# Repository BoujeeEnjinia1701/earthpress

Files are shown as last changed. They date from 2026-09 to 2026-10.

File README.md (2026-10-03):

# EarthPress

     

**Area:** Sustainable Housing · **TRL:** 3 of 9 (proof of concept on paper) · **Value-engineering target:** about $500 USD (estimated parts cost $523) · **Difficulty:** 3 of 5

A manual compressed earth block press with a lever and toggle linkage, producing stabilized soil blocks for low-carbon walls, with a simple soil test kit to choose mixes.

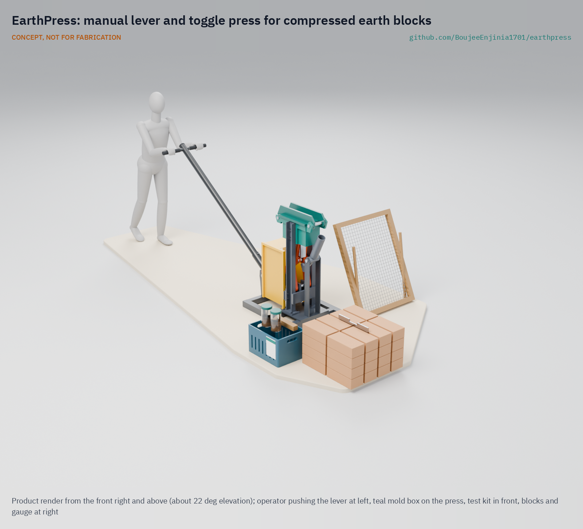
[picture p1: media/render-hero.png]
EarthPress: manual lever and toggle press for compressed earth blocks, product render


[Exploded render](media/render-exploded.png) · [Detail render](media/render-detail.png) · [Interactive 3D model](media/viewer.html) · [Concept blueprint (PDF)](media/concept-blueprint.pdf) · [General arrangement (PDF)](cad/drawings/EPR-DWG-001.pdf) · [Sizing note](docs/04-calcs/01-sizing.md) · [Decisions](docs/decisions/0002-recommendations-accepted.md) · [Prototype build plan](docs/05-build-plan.md) · [Design decisions](docs/06-design-decisions.md) · [Review note](docs/REVIEW.md)

## Concept rationale

Compressed stabilized earth blocks turn the soil on a building site into walling with a fraction of the energy of fired brick, but only if someone has a press. A manual lever and toggle press needs no fuel, power or hydraulics, can be welded from stock steel sections, and puts block making in the hands of the builder instead of a factory. The toggle suits the job because soil gets stiffer as it compacts, and a toggle's force ratio rises sharply at the end of its stroke, exactly where the force is needed.

EarthPress is open hardware so that a local welder can build, repair and adapt it without license fees or a distant supplier, and so that the soil test kit and mix guidance travel with it. The press and soil kit come to about $523 in parts (indicative), well below the thousands of dollars of hydraulic designs, and garage-buildable with a stick welder, grinder and drill press.

## Burning platform

Buildings and construction account for about 32 % of global energy use and 34 % of global CO2 emissions ([UNEP, 2025](https://www.unep.org/resources/report/global-status-report-buildings-and-construction-20242025)), and cement alone for around 8 % of global CO2 ([Chatham House, 2018](https://www.chathamhouse.org/2018/06/making-concrete-change-innovation-low-carbon-cement-and-concrete)). At the same time UN-Habitat estimates that about 3 billion people will need adequate housing by 2030, about 96,000 new affordable homes every day ([UN-Habitat](https://unhabitat.org/topic/housing)).

Meeting that demand with fired brick and cement block would lock in large emissions. Cement-stabilized earth blocks embody about 49 kg CO2/m³ against about 643 kg CO2/m³ for locally fired bricks ([Auroville Earth Institute](https://www.earth-auroville.com/compressed_stabilised_earth_block_en.php)), so the walls of a small house (about 7 m³ of blockwork) would avoid roughly 4.2 t of CO2 (estimate from EPR-CAL-001, excluding mortar and transport).

## Where it could be used

### By industry

| Industry | Use |
| --- | --- |
| Self-build and affordable housing | Families and cooperatives make walling for one- and two-room houses from site soil |
| Small construction enterprises | A block yard sells stabilized blocks to local builders as a business |
| Humanitarian and reconstruction programs | NGOs train masons and build schools, clinics and transitional-to-permanent housing |
| Agriculture | Farm stores, grain stores, animal shelters and boundary walls |
| Vocational education | Technical colleges teach earth building, soil testing and press fabrication |
| Low-carbon architecture in high-income countries | Garden walls, studios and small buildings where earthen codes allow CEB |

### By country or region

| Country or region | Why it matters there |
| --- | --- |
| Sub-Saharan Africa | 265 million people lived in slums in 2022, with an estimated 360 million more by 2030 if trends persist ([UN SDG Report 2024](https://unstats.un.org/sdgs/report/2024/Goal-11/)); soil is abundant and cement is costly |
| India and South Asia | Central and Southern Asia had 334 million slum dwellers in 2022 ([UN SDG Report 2024](https://unstats.un.org/sdgs/report/2024/Goal-11/)); India is home to the Auroville Earth Institute, a long-running center of CSEB practice, and fired-brick kilns are widespread |
| Eastern and South-Eastern Asia | The largest slum population, 362 million people in 2022 ([UN SDG Report 2024](https://unstats.un.org/sdgs/report/2024/Goal-11/)) |
| Colombia and Latin America | Soil-cement blocks were used in Colombian projects by the 1940s, and the CINVA-Ram manual press, designed at CINVA in Bogotá in 1956, spread to Bolivia, Brazil, Peru and beyond ([Botti, *Frontiers of Architectural Research*, 2023](https://www.sciencedirect.com/science/article/pii/S2095263523000584)) |
| United States (New Mexico) | The 2021 New Mexico Earthen Building Materials Code covers CEB and requires 300 psi (about 2.1 MPa) compressive strength ([14.7.4 NMAC](https://www.srca.nm.gov/parts/title14/14.007.0004.html)) |

## What sparked the idea

The starting point was the CINVA-Ram, the steel lever press that Chilean engineer Raúl Ramírez designed in 1956 at the Inter-American Housing Center (CINVA) in Bogotá and patented in 1958. Self-help housing programs then carried it as far as Ghana and South Vietnam, showing that one hand-operated press could put earth-block walls within reach of families building their own homes ([Botti, *Frontiers of Architectural Research*, 2023](https://www.sciencedirect.com/science/article/pii/S2095263523000584)). Seventy years on, that pattern still has no open, dimensioned and calculated successor that a local welder can build, while the best-documented open press, the Open Source Ecology CEB Press, is hydraulic and costs $3,000 to $6,500 in materials ([OSE wiki](https://wiki.opensourceecology.org/wiki/CEB_Press)). EarthPress sets out to update the CINVA-Ram idea with a toggle sized by calculation, a soil test kit and open drawings.

## Problem

Fired bricks and cement blocks carry high embodied carbon and cost; compressed earth blocks are proven but good presses are expensive or hard to source. Design with, not for: requirements must come from co-design sessions with builders and masons through a local partner (see [docs/01-problem.md](docs/01-problem.md)).

## Concept

A manual compressed earth block press with a lever and toggle linkage, producing stabilized soil blocks for low-carbon walls, with a simple soil test kit to choose mixes. A 1.7 m lever drives a toggle under the piston to compact a weighed fill of moist, sieved soil into a 290 x 140 x 90 mm block at 2 MPa (81 kN); the same lever, moved to an eject socket, pushes the block out. The TRL 3 sizing note (EPR-CAL-001) gives a force ratio of 173:1 at the stop and a peak pull of 668 N, so two people share the lever on a T-handle. Estimates: about 296 blocks a day with a crew of four, and, since the design was made buildable on 2026-10-01 ([EPR-DDR-003](docs/decisions/0003-design-for-construction.md)), a press of about 200 kg in pieces of 45 kg or less and about $523 in parts. Against the targets Amish accepted on 2026-09-25 ([EPR-DDR-002](docs/decisions/0002-recommendations-accepted.md)), R7 is met on paper against the 200 kg total, including the guard and bolts, that Amish set on 2026-10-02 (see the [design decisions register](docs/06-design-decisions.md)), and R13 is USD 23 over its $500 value-engineering target; R2 (pressure) and R4 (output) are at risk. See the [review note](docs/REVIEW.md).

Full design precis: [docs/02-concept.md](docs/02-concept.md)

## Key components

1. Frame on skids, in two bolted pieces
2. Steel mold box
3. Ribbed lid with hinge and latch
4. Piston and push rod
5. Toggle links, pins and bushes
6. Lever, crank hub and T-handle (removable)
7. Eject lever, rest catch and end pawl
8. Soil sieve, 5 mm mesh
9. Soil test kit
10. Block gauge

The priced bill of materials is in [bom/bom.csv](bom/bom.csv) (13 lines; lines 11 to 13 are hardware, consumables and the linkage guard). Numbers match the [exploded view](media/exploded.png). Geometry comes from the parametric model in [cad/src/model.py](cad/src/model.py), with STEP and STL exports in `cad/step` and `cad/stl`.

## Building the prototype

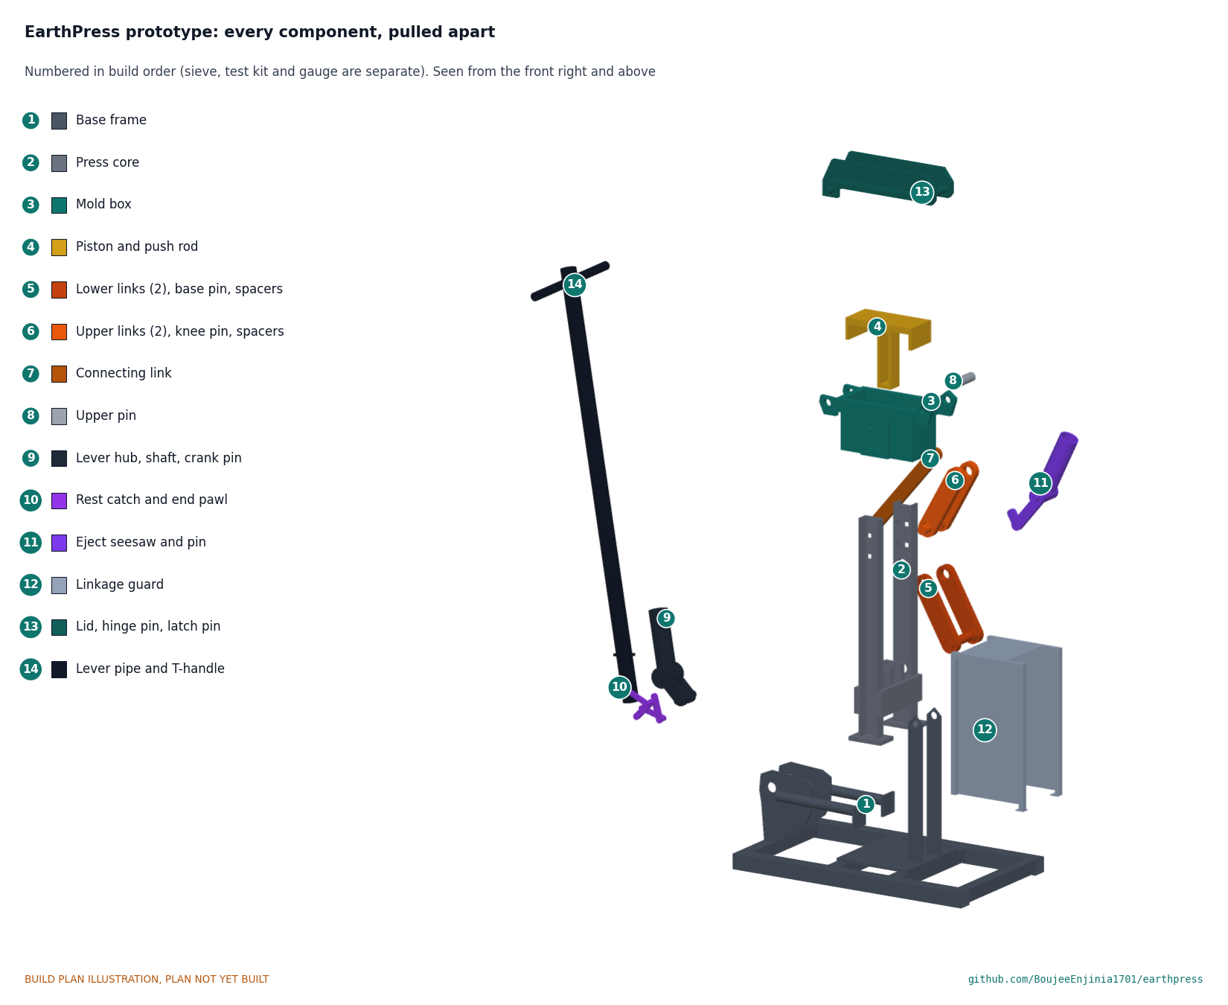
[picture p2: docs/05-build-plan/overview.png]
EarthPress prototype: every component pulled apart and numbered in build order


The [prototype build plan](docs/05-build-plan.md) (EPR-BLD-001) shows how to make each of the 14 press components and fit them together in 13 steps, with a making sketch for every made part (EPR-DWG-101 to 115) and a picture of every joint and step. The press is welded from plate, UPN 80 channel, tube and pipe in a small fabrication shop; the turned pins, shaft and bushes are bought. Making the concept buildable changed how parts join, not what the press does: the columns face the mold with their webs, the lid's hinge and latch are pins through rib ears, a spring catch and pawl hold the crank, and a central arm ejects the block ([EPR-DDR-003](docs/decisions/0003-design-for-construction.md)). It is a plan, not yet built; building and testing to it is TRL 4 work.

## Safety

> High lever forces: the piston applies 81 kN at 2 MPa and up to 173 kN if two people pull hard at the stop. Keep hands clear of the mold, linkage and eject arm, engage the end pawl before letting go (the lever kicks back with about 47 J), and never unlatch the lid until the lever is back on its rest stop. Cement burns skin and eyes, and sieving dry soil raises silica dust: wear gloves, eye protection and a respirator. Use two-person lifting for the press parts (up to 45 kg each). Blocks are not certified; structural use needs an engineer and block tests under the local code. See the safety section of [docs/02-concept.md](docs/02-concept.md).

## Repository layout

| Folder | Contents |
| --- | --- |
| `docs/` | Problem, concept, requirements, calculations and design decisions |
| `cad/src/` | build123d Python source, the source of truth for all geometry |
| `cad/step/`, `cad/stl/` | Exported models for FreeCAD, other CAD tools and printing |
| `cad/drawings/` | 2D sketches and dimensioned drawings |
| `bom/` | Bill of materials |
| `electronics/` | KiCad schematics and PCB layouts |
| `firmware/` | Microcontroller code |
| `media/` | Renders, perspectives and photos |
| `build-log/` | Dated prototyping notes |

## Documentation

Controlled documents follow the portfolio [documentation standard](.kit/STANDARDS.md). Each carries a document ID (EPR-PRC-001 for the precis), a version and a revision history. Branded PDFs are built with `python .kit/render.py` and attached to GitHub Releases when a document is tagged, for example `EPR-PRC-001/v1.0`.

## Credits

Designed by Amish Chadha, with contributions from Ashok Kumar Chadha. See [CONTRIBUTORS.md](CONTRIBUTORS.md) for roles. To cite this design, use [CITATION.cff](CITATION.cff) (GitHub shows it as "Cite this repository").

AI assistance (Claude) was used to accelerate concept renders, prototype documentation and first-pass sizing calculations. Design direction and all decisions are Amish Chadha's, recorded in this repository's decision records (`docs/decisions/`).

## Licenses

- **Hardware** (CAD, drawings, BOM, electronics): [CERN-OHL-S v2](LICENSE)
- **Software** (firmware, scripts, notebooks): [MIT](LICENSE-SOFTWARE)

A project of the [Design Molecule](https://designmolecule.com) lab.

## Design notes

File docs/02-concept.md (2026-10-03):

---
doc_id: EPR-PRC-001
title: EarthPress design precis
project: EarthPress
doc_type: Design precis
version: "0.8"
status: Draft
date: '2026-10-02'
author: Amish Chadha
license: CERN-OHL-S-2.0
revisions:
- version: "0.1"
  date: '2026-09-25'
  author: Amish Chadha
  change: Initial scaffold
- version: "0.2"
  date: '2026-09-25'
  author: Amish Chadha
  change: Populate to TRL 2 (architecture, first-order numbers, safety, media, open questions)
- version: "0.3"
  date: '2026-09-25'
  author: Amish Chadha
  change: TRL 3 update from EPR-CAL-001 and EPR-DDR-001 (linkage geometry, two-person T-handle, separate eject lever, ribbed lid, weighed fill, masses, cost, safety)
- version: "0.4"
  date: '2026-09-25'
  author: Amish Chadha
  change: Recommendations accepted by Amish (DDR-002)
- version: "0.5"
  date: '2026-10-01'
  author: Amish Chadha
  change: Constructable design (EPR-DDR-003); mass, cost, latch, catch and eject arm updated; open questions moved to the design decisions register (EPR-DEC-001)
- version: "0.6"
  date: '2026-10-01'
  author: Amish Chadha
  change: Budget treated as a value-engineering target
- version: "0.7"
  date: '2026-10-02'
  author: Amish Chadha
  change: "Decisions of 2026-10-02: R7 total 200 kg; weighed fill and scoop rule; softer design soil for the chart; bush dust seals; lime option; plain mold walls measured against R8"
- version: "0.8"
  date: '2026-10-02'
  author: Amish Chadha
  change: 'Cost USD 523 with the dust seals (R13 over by USD 23); R7 199.996 kg; operating chart and lime chart in the build plan section 3.15'
---

# EarthPress design precis

## Summary

EarthPress is a manual press, welded from common steel sections, that compacts moist, sieved and cement-stabilized site soil into 290 x 140 x 90 mm blocks with a 1.7 m lever driving a toggle linkage under the mold. The TRL 3 calculation (EPR-CAL-001) shows that the linkage reaches the 81.2 kN needed for 2 MPa with a force ratio of 173:1 at the stop, but that the peak pull is 668 N, so **two people share the lever on a T-handle**. Each fill is **weighed** to within about 200 g, because the pressure reached at the stop is sensitive to fill mass. The block is ejected with the same lever moved to a separate eject socket. A crew of four could make about 296 blocks a day (8.9 m² of 140 mm wall). Made buildable on 2026-10-01 (EPR-DDR-003), the press weighs about 200 kg, its heaviest piece 45 kg, and the press and kit cost about $523 in parts. Against the targets Amish accepted on 2026-09-25 (EPR-DDR-002), R5 (334 N per operator) is met on paper, R7 is met on paper against the 200 kg total (including the guard and bolts) that Amish set on 2026-10-02 (EPR-DEC-001), R13 is over its value-engineering target (estimated $523 against a $500 target, USD 23 over), and R2 and R4 are at risk. All values are estimates.

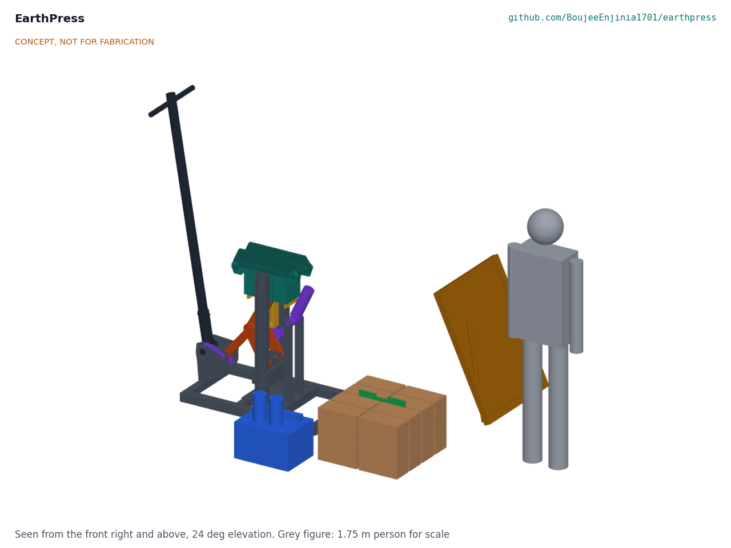
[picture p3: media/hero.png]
Hero render


*Figure 1. EarthPress at the start of the stroke, with its soil sieve, test kit, a stack of blocks with the block gauge, and a 1.75 m person for scale. Concept model, not for fabrication.*

## How it works

1. **Test.** The soil test kit screens site soil with a jar sedimentation test (sand, silt and clay fractions), a shrinkage box (linear shrinkage), and ribbon and drop tests. A printed chart turns the results into go or no-go and a starting cement content, usually 5 % by dry mass, following Auroville Earth Institute practice ([Auroville Earth Institute](https://www.earth-auroville.com/compressed_stabilised_earth_block_en.php)).
2. **Sieve and mix.** The crew throws dry soil through a 5 mm mesh sieve leaning on a prop, measures soil and cement by bucket, mixes them dry, then adds about 10 % water until a squeezed ball holds its shape and breaks cleanly when dropped.
3. **Weigh and fill.** With the lever on its rest stop, held there by the rest catch, and the lid open, the piston sits at the bottom of its stroke. The operator weighs every fill on the 10 kg scale (a calibrated scoop is allowed only for a soil whose scoop-to-mass scatter has been measured within the 0 to 2.7 % fill window) to the target on the chart (about 7.74 kg for the reference soil, +1.3 % ± 100 g), tips it into the 290 x 140 mm mold, levels it about 150 mm deep, closes the lid and pushes the latch pin in.
4. **Press.** One operator lifts the rest catch; two people pull the T-handle down from about 1.9 m to about 0.86 m. A 107 mm crank on the lever hub pushes a 420 mm connecting link against the knee of the toggle, which straightens from 29° to 6° from vertical and lifts the piston 60 mm. The force ratio climbs from about 15:1 to 173:1, so the force arrives where the soil is stiffest; the peak pull, 668 N in total, comes about 3 mm before the crank stop, at waist height. The end pawl drops in under the crank pin at the stop.
5. **Eject.** The operators hold the lever, lift the pawl and return the lever to its rest stop, where the catch drops in; this unloads the block. The latch pin is pulled and the lid swung open. The operator moves the lever to the eject socket on the +X side and pulls down: the round nose of the seesaw's arm lifts the push rod 160 mm, the rod rising past the toggle pin in its 200 mm slot, which pushes the block flush with the rim at about 470 N on the grip. The block is lifted off, checked with the block gauge and stacked in shade.
6. **Cure.** Blocks are kept damp under cover for about four weeks to let the cement hydrate, then air dried before use.

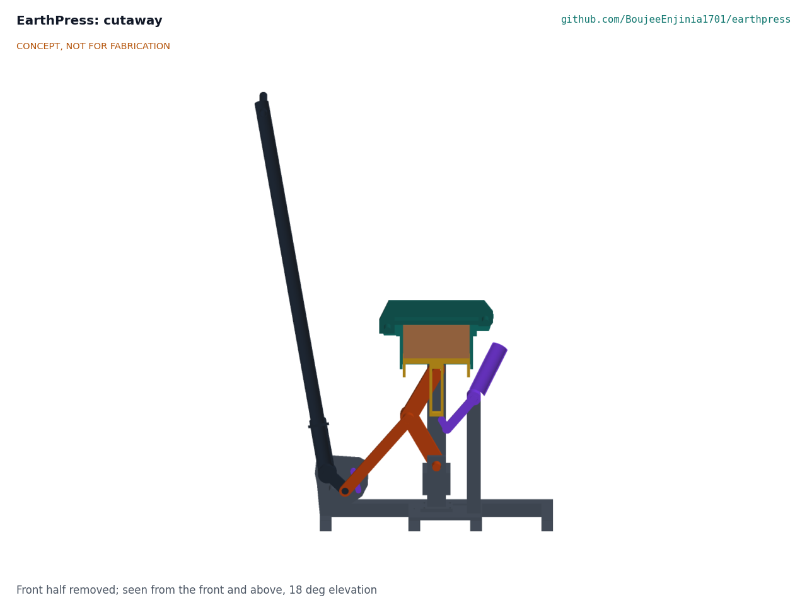
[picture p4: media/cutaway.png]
Cutaway


*Figure 2. Section through the mold and linkage at the start of the stroke: loose soil (brown) above the piston and slotted push rod (yellow), toggle links (orange), lever hub, crank and connecting link on the left, eject seesaw (purple) on the right.*

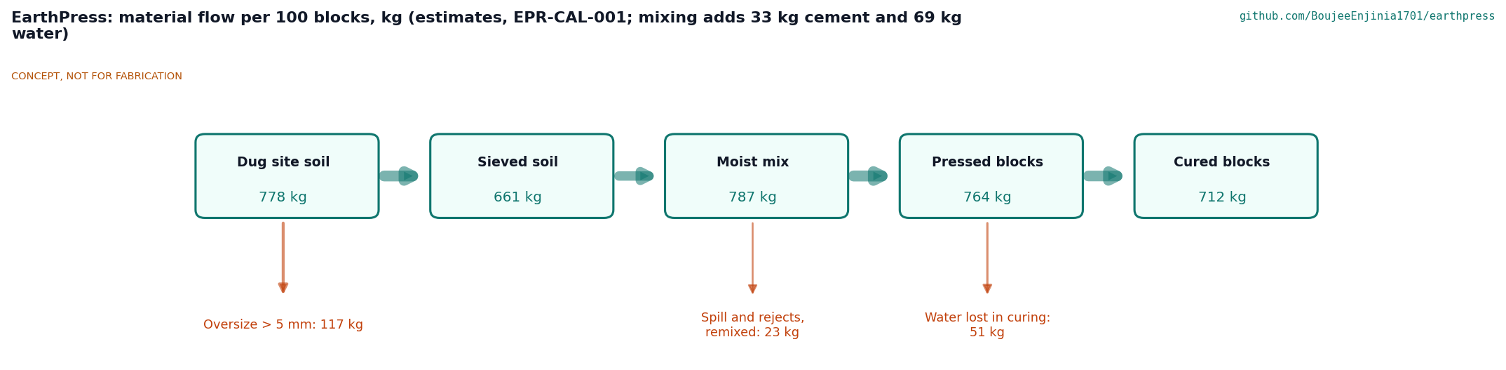
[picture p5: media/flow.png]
Material flow


*Figure 3. Material flow per 100 blocks, in kg (EPR-CAL-001 section 10). All values are estimates for a soil with 15 % oversize, 5 % cement and 10 % water.*

## Main components

Numbers match the exploded view (Figure 4) and `bom/bom.csv`. The general arrangement is drawing EPR-DWG-001 (`cad/drawings/EPR-DWG-001.pdf`).

*Table 1. Components.*

| # | Component | Choice | Notes |
| --- | --- | --- | --- |
| 1 | Frame, in two bolted pieces | Base: 60 x 60 x 3 mm tube skids 1.0 m long, 50 x 50 mm cross tubes flush with the skids, 12 mm base plate, shaped lever bracket plates with a rest stop bar, tie tubes bolted to the core, eject posts. Core: two UPN 80 columns, webs toward the mold, with pin access holes, and a base beam of two 20 x 100 mm plates with lugs carrying the toggle base pin | The press force closes through the core and mold; the base only carries weight and the lever reaction. 45.0 and 28.2 kg |
| 2 | Mold box | 12 mm plate round a 290 x 140 x 200 mm cavity, 16 x 50 mm belt round the top, side flanges tapped for eight M16 8.8 bolts through the column webs, hinge and latch lugs | 30.4 kg |
| 3 | Lid with hinge and latch | 20 mm plate with two 20 x 70 mm ribs cut long as ears for the 30 mm hinge pin and the 30 mm latch pin | Rated for 173 kN; 27.0 kg with pins |
| 4 | Piston and push rod | 25 mm plate with two end skirts on a 60 mm square rod with a 200 mm lost-motion slot | Clearance about 1 mm per side in the mold |
| 5 | Toggle linkage | Four 28 x 70 mm round-ended links, 245 mm between centers; 24 x 50 mm connecting link, 420 mm; three 35 mm C45 pins in case-hardened steel bushes with grease nipples and felt or rubber dust seals at the bush faces, with spacers | Crank stop at 6° limits the force to 173 kN |
| 6 | Lever, crank hub and T-handle | 1.7 m of 2 in schedule 40 pipe in a socket on a hub with a 107 mm crank; pivot at 266 mm height, 468 mm from the piston axis; 0.5 m T-handle | Removable; the same pipe fits the eject socket |
| 7 | Eject lever, rest catch and end pawl | Seesaw with a central arm whose round nose lifts the push rod, 160 mm from its pivot on the +X side; spring catch and pawl that hold the crank pin at the start and the end of the stroke | Eject ratio 10.3:1 |
| 8 | Soil sieve | 5 mm welded mesh in a 700 x 900 mm timber frame on a prop | Removes stones and clods |
| 9 | Soil test kit | Two 1 L clear jars, a 600 x 40 x 40 mm shrinkage box, measuring buckets, 10 kg scale with 50 g divisions, printed chart | Field tests only (EPR-DDR-001 item 7) |
| 10 | Block gauge | Bar with legs 292 mm apart and a 93 mm notch, for length and height | Checks every block |

BOM lines 11 to 13 (hardware and paint, consumables, and an expanded-metal guard over the crank, connecting link and knee) have no callout.

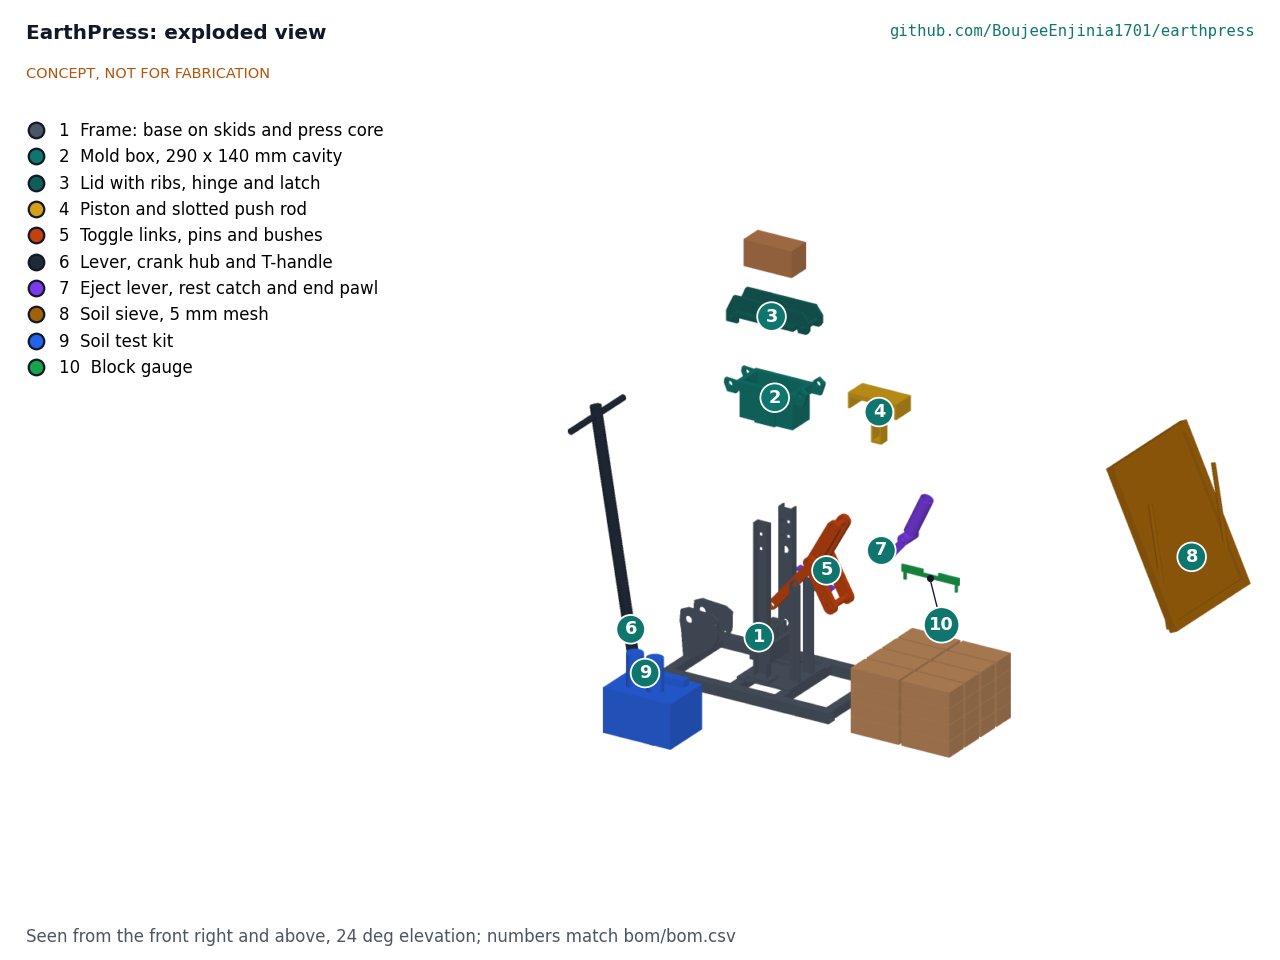
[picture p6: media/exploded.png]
Exploded view


*Figure 4. Exploded view with callouts matching the BOM. Loose soil and the block stack are context only.*

## Key numbers

All values are estimates from EPR-CAL-001, where the assumptions are stated.

*Table 2. Key numbers.*

| Quantity | Value | Basis |
| --- | --- | --- |
| Block force for 2 MPa | 81.2 kN (8.3 tonne-force) | 2 MPa x 0.0406 m² |
| Block volume and mass | 3.65 L; 6.94 kg dry, 7.64 kg moist | Dry density 1,900 kg/m³ (assumed) |
| Force ratio | 14.8:1 at the start, 20.0:1 at 30 mm, 173:1 at the stop | Toggle 29.3° to 6.0°, lever arc 59.2° |
| Peak pull at the grip | 668 N (334 N each for two); 571 to 809 N for stiffer or softer soil; the operating chart uses the softer soil (809 N, 405 N each) until partner soils are measured | Soil pressure rising tenfold over the last 14 mm (assumed) |
| One operator at 500 N | Stalls at 0.53 MPa | The peak comes before the stop |
| Compaction work | 494 J (353 to 705 J) | Same soil law |
| Fill window for 2 MPa at the stop | 0 to +2.7 % of nominal (0 to 206 g) | Two operators |
| Design load for the structure | 173 kN (4.26 MPa on the block) | 1,000 N at the grip at the stop |
| Lowest safety factor at 173 kN | 1.13 (bush bearing); lid 1.61, base beam 1.60, lever 1.57 | EPR-CAL-001 Table 5 |
| Kickback energy if released at the stop | 47 J | 1 mm soil rebound plus column stretch |
| Eject force and grip force | 4.84 kN; 470 N | 0.1 MPa residual wall pressure, friction 0.6 (assumed) |
| Output | 296 blocks per day, crew of four; 8.9 m² of wall | 85 s cycle (assumed) |
| Small house, 50.5 m² of wall | 1,683 blocks, 5.7 press days, 556 kg cement (11.1 bags) | 22 m perimeter, 2.7 m walls, 15 % openings |
| Embodied CO2 of that wall | 0.35 t as CSEB against 4.55 t as fired brick (7.6 %) | 49 and 643 kg CO2/m³ ([Auroville Earth Institute](https://www.earth-auroville.com/compressed_stabilised_earth_block_en.php)); excludes mortar and transport |
| Press mass | 199.996 kg with guard, bolts and dust seals; heaviest piece 45.0 kg | Model volumes at 7,850 kg/m³ |
| Parts cost | $523 (indicative; USD 23 over the $500 value-engineering target; includes $3 of dust seals) | `bom/bom.csv` |

## Key design choices

All of these choices were decided by Amish on 2026-09-25: go with recommendation (EPR-DDR-001, EPR-DDR-002).

- **Bottom piston with a toggle and one lever**, following the CINVA-Ram pattern rather than a screw, a bottle jack or a top-down ram. It needs no hydraulic parts and a welder can build and repair it.
- **Flat 290 x 140 x 90 mm block**, the module used by the Auroville Earth Institute. Interlocking molds could follow as inserts.
- **2 MPa compaction target**, the low end of CSEB practice.
- **Cement stabilization at 5 % by default**, with lime as a documented option for clay-rich soils or where cement is scarce, with its own mix chart and a longer curing period; the press and its dwell are the same (decided 2026-10-02).
- **Plain 12 mm mold walls** for the prototype; their wear is measured against R8, and bolt-on hardened liners are designed only if the measured rate would not last 50,000 sandy blocks (decided 2026-10-02).
- **Field soil tests only**, with no lab equipment.
- **Bolted frame and mold with a 12 mm base plate**, so the press splits into pieces of 45 kg or less.
- **Longer arc from a low pivot**: the lever starts nearly upright, which gives 59° of arc with the grip between 0.86 and 1.89 m. Raising the pivot to 800 mm for a 100° arc, as proposed at TRL 2, would take the grip below the ground.
- **Two operators on a T-handle**, since one person at 500 N stalls at 0.53 MPa.
- **Separate eject seesaw with a lost-motion slot**, because a toggle ending near straight cannot lift the piston another 90 mm.
- **Crank stop at the design end angle and a weighed fill**, which caps the force at 173 kN and fixes the block height at 90 mm.

## Safety

> **Safety:** The press applies 81 kN (over 8 tonne-force) at the piston, and up to 173 kN if two people pull hard at the stop. Keep hands out of the mold, the linkage and the eject arm while anyone is on a lever. Only the people on the lever touch it, and only after calling "clear". Keep the linkage guard in place.

> **Safety:** Released at the end of the stroke, the lever kicks back with about 47 J. Engage the end pawl before letting go, return the lever to its rest stop under control, keep heads out of the lever arc and never stand on the lever.

> **Safety:** Never unlatch the lid while the lever is loaded. Return the lever to the rest stop first. The lid and latch are sized for 173 kN, but a worn latch or a missing pin can throw the lid and soil upward.

> **Safety:** Portland cement is alkaline and can burn skin and eyes. Wear gloves, long sleeves and eye protection when mixing. Sieving dry soil raises dust that may contain respirable crystalline silica; sieve damp soil where possible, work upwind and wear an FFP2 or N95 respirator.

> **Safety:** A moist block weighs about 7.6 kg, the lid 27 kg on its hinge and the press 200 kg. Lift blocks close to the body, rotate tasks in the crew, and move the press dismantled, two people to each piece.

> **Safety:** Blocks made by EarthPress are not certified. Walls in seismic zones, multi-storey walls and any building that needs a permit require a structural design and block tests by a qualified engineer under the local building code.

> **Safety:** Building the press involves welding, grinding and cutting. Use welding PPE, guard grinders and work away from flammables.

## Open questions

Open decisions and questions are kept in the design decisions register, `docs/06-design-decisions.md` (EPR-DEC-001).

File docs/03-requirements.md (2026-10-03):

---
doc_id: EPR-REQ-001
title: EarthPress requirements
project: EarthPress
doc_type: Requirements
version: "0.8"
status: Draft
date: '2026-10-02'
author: Amish Chadha
license: CERN-OHL-S-2.0
revisions:
- version: "0.1"
  date: '2026-09-25'
  author: Amish Chadha
  change: Initial scaffold
- version: "0.2"
  date: '2026-09-25'
  author: Amish Chadha
  change: First measurable requirements for TRL 2, with status against the concept estimates
- version: "0.3"
  date: '2026-09-25'
  author: Amish Chadha
  change: Status of every requirement from EPR-CAL-001; reference block and 2 MPa target adopted for TRL 3 (EPR-DDR-001); proposed revisions to R5, R7 and R13 listed, awaiting Amish
- version: "0.4"
  date: '2026-09-25'
  author: Amish Chadha
  change: "Recommendations accepted by Amish (DDR-002): R5 reworded, R7 total relaxed to 190 kg, R13 at $500; status from EPR-CAL-001 v0.2"
- version: "0.5"
  date: '2026-10-01'
  author: Amish Chadha
  change: Status from EPR-CAL-001 v0.3 for the constructable design (EPR-DDR-003); R7 and R13 not met, open decisions in EPR-DEC-001
- version: "0.6"
  date: '2026-10-01'
  author: Amish Chadha
  change: Budget treated as a value-engineering target
- version: "0.7"
  date: '2026-10-02'
  author: Amish Chadha
  change: "R7 total set at 200 kg including the guard and bolts (EPR-DDR-003 A1, 2026-10-02), now met on paper; R5 status gives the softer design soil"
- version: "0.8"
  date: '2026-10-02'
  author: Amish Chadha
  change: 'R7 met at 199.996 kg including the dust seals; R13 over the target by USD 23 ($523) after the dust seals'
---

# EarthPress requirements

These requirements are checked by calculation in EPR-CAL-001 (TRL 3). On 2026-09-25 Amish accepted the TRL 3 recommendations (EPR-DDR-002), so R5, R7 and R13 carry the revised targets; the earlier targets are listed under "Revisions accepted" below. Targets still need validation with users in co-design sessions (see EPR-PRB-001).

The **reference block** is 290 x 140 x 90 mm, about 3.65 L and 6.94 kg dry, from a sandy clay loam stabilized with 5 % cement by dry mass (block size, 2 MPa target and stabilizer decided by Amish, 2026-09-25: go with recommendation; EPR-DDR-001 items 3 to 5, EPR-DDR-002).

*Table 1. Requirements and status at TRL 3 (EPR-CAL-001 v0.2).*

| ID | Requirement | Target | Verification (TRL 3 or later) | Status (EPR-CAL-001) |
| --- | --- | --- | --- | --- |
| R1 | Block dimensions | 290 x 140 mm ± 2 mm on plan; height 90 mm ± 3 mm, checked with the block gauge | Mold tolerance analysis; later gauge checks on a production run | Met on paper: 90.0 mm at the crank stop when the fill is within 0 to +2.7 %; mold bulge 0.08 mm |
| R2 | Compaction pressure | 2.0 MPa or more on the block face at the end of the stroke | Linkage force calculation | **At risk:** 81.2 kN reached with two operators (peak 668 N at the grip) and a weighed fill; one operator at 500 N stalls at 0.53 MPa |
| R3 | Block strength with suitable soil | 28-day dry compressive strength 4 MPa or more and wet strength 2 MPa or more (Auroville class B); in all cases 2.1 MPa (300 psi) or more, as in 14.7.4 NMAC | Literature review at TRL 3; block tests at TRL 4 | Not verifiable at TRL 3 |
| R4 | Output | 300 or more blocks in an 8 h day with a crew of four, including mixing | Cycle time estimate; later timed trials | **At risk:** 296 blocks a day at an assumed 85 s cycle |
| R5 | Operator force | Peak pull of 500 N or less per operator at the lever grip; grip between 0.8 and 1.9 m above ground through the stroke, with the peak force at 1.0 m or higher | Force calculation; ergonomic check of the lever arc | Met on paper with two operators: 334 N each (668 N total) at 1.16 m for the base soil, and 405 N each (809 N total) for the softer soil on which the operating chart is based until partner soils are measured (2026-10-02); grip 0.86 to 1.89 m. Eject 470 N for one |
| R6 | Garage-buildable | Built with a stick welder, angle grinder, drill press and hand tools; no turned or milled parts except purchased pins and bushings | Design review of every part | Met (design review): turned pins, shafts and bushes are bought |
| R7 | Movable | Complete press 200 kg or less, including the guard and bolts (relaxed from 190 kg, EPR-DDR-003 A1, 2026-10-02); no single piece over 50 kg after removing pins and bolts; fits a 1.5 m pickup bed | Mass estimate from the model | Met on paper: 199.996 kg in total with the guard, bolts and dust seals against the 200 kg total set on 2026-10-02 (a 4 g margin, so the weighed prototype decides); heaviest piece 45.0 kg, met; plan 1.28 x 0.58 m |
| R8 | Durability | 50,000 blocks before mold liners or bushings need replacing; all pins in replaceable bushings; grease points on every pivot | Wear estimate; later endurance log | Not verifiable at TRL 3: fatigue range 89 MPa against 243 MPa allowed; wear needs soil data |
| R9 | Soil test kit | Field tests (jar sedimentation, shrinkage box, ribbon and drop tests) give a go or no-go and a starting cement content, with a first screen within 1 h and a full result within 24 h | Written procedure; later comparison with lab grading on partner soils | Met (design review); accuracy not verifiable at TRL 3 |
| R10 | Low stabilizer use | Blocks reach R3 with 8 % cement by dry mass or less; 5 % as the design target | Literature at TRL 3; block tests at TRL 4 | Not verifiable at TRL 3 (design at 5 %, 0.33 kg per block) |
| R11 | Embodied carbon | Cradle-to-gate CO2 of the walling material 25 % or less of a fired-brick wall of equal volume | Carbon estimate from published factors | Met on paper: 7.6 % (0.35 t against 4.55 t for a small house) |
| R12 | Safe operation | Lever cannot fall freely when released under load; lid latch holds against at least 1.5 times the peak block force; pinch points between lever and frame guarded or with 100 mm or more clearance | Design review; later proof-load test | Met on paper: rest catch and end pawl on the crank pin; lid hinge and latch pins checked at 173 kN (1.5 times is 121.8 kN); linkage guard modelled and clear of every moving part |
| R13 | Affordable | Press and test kit parts at or below the value-engineering target of $500, excluding labor and cement | Priced BOM (`bom/bom.csv`) | **Over the value-engineering target by USD 23:** $523 (indicative, with $3 of dust seals added on 2026-10-02) against the $500 target (`budget_usd`, a hypothetical control target); savings to try are in EPR-DEC-001 |
| R14 | Open and documented | CERN-OHL-S drawings, BOM and build notes sufficient for a welder to build without contacting the author | Review by an outside fabricator at TRL 3 | Not verifiable at TRL 3: no outside review yet |

## Requirements not met or at risk

Against the targets accepted on 2026-09-25, R7 was not met on paper once the design was made buildable on 2026-10-01 (EPR-DDR-003): 200 kg against 190 kg. On 2026-10-02 Amish set the R7 total at 200 kg including the guard and bolts and kept the 50 kg piece limit (EPR-DEC-001), so no requirement is now not met. One is over its value-engineering target: **R13** (estimated cost $523, USD 23 over the $500 target; the savings worth trying are in the register's Value engineering section). R2 and R4 remain at risk.

- **R2 at risk:** met only with two operators, a weighed fill (0 to +2.7 %) and the assumed soil stiffness; a softer soil (20 mm per decade) raises the peak to 809 N.
- **R4 at risk:** 296 against 300 blocks a day on an assumed cycle. Decided by Amish, 2026-09-25 (EPR-DDR-002): accept the 1 % shortfall and revisit when cycles are timed, which is TRL 4 work and on hold.
- **R3, R8, R10 and R14 cannot be verified at TRL 3.**

## Revisions accepted (EPR-DDR-002)

Decided by Amish, 2026-09-25: go with recommendation. Applied in Table 1.

- R5: was a peak pull of 500 N or less with the grip between 0.9 and 1.6 m (not met: 668 N, and the band allows only 24.5° of arc). Now 500 N or less per operator, grip between 0.8 and 1.9 m, with the peak force at 1.0 m or higher.
- R7: was 140 kg or less in total (not met: 187 kg). Now 190 kg or less; the 50 kg piece limit and pickup bed are unchanged.
- R13: was $450 or less (not met: $488). Now $500 or less, matching `budget_usd` in `project.yaml`.

## Assumptions

- Compaction pressure of 2 to 4 MPa and about 5 % cement follow Auroville Earth Institute practice ([Auroville Earth Institute](https://www.earth-auroville.com/compressed_stabilised_earth_block_en.php)).
- Dry block density about 1,900 kg/m³ (estimate), giving about 6.9 kg per dry block.
- One operator can pull 500 N at the grip for short strokes, using body weight; two can pull 1,000 N on the T-handle. To be checked with users.
- Soil pressure rises tenfold over the last 14 mm of the stroke (range 10 to 20 mm); to be measured with partner soils.
- A crew of four covers soil sieving, mixing, pressing and stacking.

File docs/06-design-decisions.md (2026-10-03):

---
doc_id: EPR-DEC-001
title: EarthPress design decisions register
project: EarthPress
doc_type: Design decisions register
version: "0.5"
status: Draft
date: '2026-10-02'
author: Amish Chadha
license: CERN-OHL-S-2.0
revisions:
- version: "0.1"
  date: '2026-10-01'
  author: Amish Chadha
  change: Register opened with the open decisions from EPR-DDR-001 to EPR-DDR-003, the precis and the build work
- version: "0.2"
  date: '2026-10-01'
  author: Amish Chadha
  change: Budget treated as a value-engineering target
- version: "0.3"
  date: '2026-10-02'
  author: Amish Chadha
  change: "Amish approved the recommendations for open decisions 1 to 8 (2026-10-02); moved to decisions made (EPR-DDR-003 A1 and A3 accepted)"
- version: "0.4"
  date: '2026-10-02'
  author: Amish Chadha
  change: "Design for construction (EPR-DDR-003, P1 to P15) accepted by Amish on 2026-10-02; the 2026-10-01 row no longer says open for review"
- version: "0.5"
  date: '2026-10-02'
  author: Amish Chadha
  change: 'Value engineering restated: USD 523 with the dust seals (USD 23 over the target)'
---

# EarthPress design decisions register

Every design decision still to be made, and every decision made, in one place. Each decision is argued in full in its decision record under `docs/decisions/`; this register is the index Amish works from. The build plan (`docs/05-build-plan.md`, EPR-BLD-001) describes the design as it stands and does not list open decisions.

## Open decisions

None. All open decisions were decided on 2026-10-02.

## To confirm when parts are bought

*Table 2. Items to confirm when parts are bought.*

| # | What to confirm | Why it matters | Source |
| --- | --- | --- | --- |
| 1 | The UPN 80 channel's web (6 mm), flange (8 mm) and depth (45 mm) | The mold bolt holes, the pin access holes and the tie bolt holes are set from them; the column webs must be 196 apart | EPR-DDR-003, P2 |
| 2 | Bushes of 35 bore and 41 outside diameter are available locally | The link and lug bores are 41; another bush size changes the bore and the net section check | EPR-DDR-003, P5 |
| 3 | A tube with about 61.3 inside diameter for the two sockets | The 2 in schedule 40 lever (60.3) must slide in without much play | EPR-BLD-001, sections 3.7 and 3.9 |
| 4 | Two small torsion springs strong enough to snap the catch and the pawl in | They make the catch and the pawl self-acting | EPR-BLD-001, section 3.8 |
| 5 | Expanded metal openings of 12 mm or less | Keeps fingers out of the guard | EPR-BLD-001, section 3.10 |
| 6 | Local prices for steel, turned pins and bushes | The BOM prices are indicative; they set the estimated cost against the value-engineering target | EPR-CAL-001, section 11 |

## Value engineering

Value-engineering target: USD 500 (a hypothetical control target, not a limit). Estimated cost of the constructable design: USD 523 (USD 23 over the target). Main cost drivers and savings worth trying:

- Steel is the main cost: 200 kg at about USD 1.30/kg is about USD 260. A lighter press (a 16 mm lid plate with deeper ribs, 10 mm mold walls, a lighter base plate, perhaps 10 kg) would save steel as well as mass; it was option (b) of the R7 mass decision, not taken on 2026-10-02, so it stays a saving worth trying.
- The parts added to make the press buildable (EPR-DDR-003) account for the rise from USD 488 to USD 520; the felt or rubber dust seals at the bush faces (decided 2026-10-02, about USD 3) take it to USD 523.
- Plain pins without bushes would save about USD 30, but R8 (wear) would fail, so this is a saving to weigh, not to take.
- Local prices for steel, turned pins and bushes are to be confirmed when parts are bought; every price is indicative.

## Decisions made

*Table 3. Decisions made.*

| Date | Decision | Decided by | Record |
| --- | --- | --- | --- |
| 2026-09-25 | TRL 2 items 1 to 7 and 9: toggle and one lever (CINVA-Ram pattern), longer arc from a low pivot, 290 x 140 x 90 mm block, 2 MPa, 5 % cement, 12 mm base plate and bolted mold, field soil tests only, no pitch change | Amish: "i accept all your recommendations, go with them across all repos." | EPR-DDR-001, EPR-DDR-002 |
| 2026-09-25 | TRL 3 items 10 to 16: separate eject seesaw with a lost-motion slot, two operators on a T-handle, R5 reworded, R7 total 190 kg, budget $500, weighed fill, linkage geometry, crank stop, ribbed lid, end pawl, linkage guard, hardened bushes, R4 at 296 blocks a day | Amish, same instruction | EPR-DDR-001, EPR-DDR-002 |
| 2026-10-01 | Design for construction: columns turned, tapped mold flanges, pin access holes and spacers, round link ends, end skirts on the piston, lid pins in rib ears, rest catch and end pawl on the crank pin, central eject arm, ties moved, guard modelled, gauge made real (P1 to P15) | Made under Amish's 2026-09-30 instruction to make the design physically buildable ("fix the design assumptions to match and be physically feasible"); the changes themselves were accepted on 2026-10-02 (below) | EPR-DDR-003 |
| 2026-10-02 | R7 total mass: option (a). The R7 total is 200 kg, defined to include the guard and bolts, and the 50 kg piece limit is kept (heaviest piece 45 kg) | Amish: "i approve your recommendations for all 555 open decisions." | EPR-DDR-003, A1 |
| 2026-10-02 | Rest catch release: option (a), hand release, for the prototype, with the build plan rule that the catch is in before the latch is opened; a foot pedal is considered only if timed cycles (R4) show the extra step costs output | Amish: "i approve your recommendations for all 555 open decisions." | EPR-DDR-003, A3 |
| 2026-10-02 | First co-design partner: one that already trains builders in stabilized earth blocks and has local soils and cement supply. First candidate to approach: the Auroville Earth Institute in India, whose 290 x 140 x 90 mm block module the press uses | Amish: "i approve your recommendations for all 555 open decisions." | EPR-DDR-001, item 8 |
| 2026-10-02 | Bushes: case-hardened steel with grease nipples, as decided (EPR-DDR-002, item 16f), with simple felt or rubber dust seals added at the bush faces; bronze or UHMW-PE revisited only if TRL 4 wear data show scoring | Amish: "i approve your recommendations for all 555 open decisions." | EPR-PRC-001, open questions |
| 2026-10-02 | Mold wear: build the prototype with plain 12 mm mold walls and measure their wear against R8; bolt-on hardened liners are designed only if the measured rate would not last 50,000 sandy blocks | Amish: "i approve your recommendations for all 555 open decisions." | EPR-PRC-001, open questions |
| 2026-10-02 | Fill: weigh every fill, as decided (EPR-DDR-002, item 15); a calibrated scoop is allowed only for a soil whose scoop-to-mass scatter has been measured within the 0 to 2.7 % fill window | Amish: "i approve your recommendations for all 555 open decisions." | EPR-PRC-001, open questions |
| 2026-10-02 | Stabilizer: cement stays the default; lime is a documented option with its own mix chart and a longer curing period; no change to the press or its dwell | Amish: "i approve your recommendations for all 555 open decisions." | EPR-PRC-001, open questions |
| 2026-10-02 | Design soil: the operating chart is based on the softer soil (809 N peak, 405 N per operator, within R5's 500 N) until partner soils are measured, then each soil gets its own figure | Amish: "i approve your recommendations for all 555 open decisions." | EPR-PRC-001, open questions |
| 2026-10-02 | Design for construction accepted: the changes P1 to P15, as made | Amish: "APPROVED: Design-for-construction changes in 10 repos (CityTwin, CoolShade, PalletPilot, Heliolite, PotholeLog, EarthPress, ReadyKit, CellCheck, CargoMule and ThermaCart)" | [EPR-DDR-003](decisions/0003-design-for-construction.md), Table 1 |

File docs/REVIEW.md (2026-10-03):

# Review note: EarthPress

## Session 2026-10-01: constructable design and prototype build plan (kit 1.7.0)

Kit 1.7.0 installed (`.kit/`, `.claude/commands/`, `CLAUDE.md`). The design was checked for construction with build123d and made buildable under Amish's 2026-09-30 instruction ("fix the design assumptions to match and be physically feasible"); every change is in `docs/decisions/0003-design-for-construction.md` (EPR-DDR-003, Draft, open for his review).

### Design changes made for construction

- P1 Base frame: cross tubes flush with the skid tops and two of them under the base plate (the plate floated); base plate 315 x 340 mm, carrying the eject posts.
- P2 Columns turned so the webs face the mold; mold flanges tapped M16 and bolted from inside the channel (no room for a nut before); beam plates moved to the outside of the column flanges; base pin lugs welded between them (they floated); column feet bolted with 4 x M12 each.
- P3 Push rod guide strap removed (it sat in the path of the upper links and pin); two 12 mm end skirts under the piston keep it square; upper pin shortened to 128 mm (its ends passed through the mold walls).
- P4 40 mm access holes in the +Y column web for the base pin and the upper pin, and a 31 mm access hole in the +Y lever bracket plate for the crank pin (none could be fitted before); spacer tubes on the base and knee pins.
- P5 Round ends on every link and pressed-in 41 mm bushes (the links stopped at the pin centres).
- P6 Lid hinge: the lid ribs are cut long as ears on a 30 mm pin between two lugs on the mold (the knuckle cut into the belt and had no pin).
- P7 Latch: a 30 mm pin with a T-handle through the rib ears and two mold lugs (the hook sat above its keeper).
- P8 Rest stop bar under the crank; spring rest catch (-Y) and end pawl (+Y) on the crank pin (the old rest bar blocked the stroke and the pawl could not reach the lever).
- P9 Eject: one central cranked arm with a round nose under the push rod's foot, pivot at 607.5 mm (the fork and foot pin crossed the upper links at the end of the stroke).
- P10 Ties moved out to 90 mm off the centre line and bolted to the beam with tabs (they ran through the crank pin's path).
- P11 Linkage guard modelled and fixed (it was only in the BOM).
- P12 Lever pipe starts clear of the hub; 12 mm locking pin. P13 Hub washers and circlips. P14 Block gauge made real (legs 292 mm apart, 93 mm notch). P15 Bracket plates reshaped.

`cad/src/model.py` now builds each part on its own and runs 47 constructability checks at seven poses (`python cad/src/model.py --check`); all pass.

### What was done

- `docs/05-build-plan.md` (EPR-BLD-001 v0.1) with `cad/src/build_plan_media.py`: overview, 15 making sketches (`cad/drawings/EPR-DWG-101` to `115`), 11 joint pictures and 13 step pictures in `docs/05-build-plan/`.
- `docs/06-design-decisions.md` (EPR-DEC-001 v0.1): 9 open decisions (8 after the 2026-10-01 budget wording pass), 6 items to confirm when parts are bought, decisions made. The precis's open questions moved there.
- Regenerated: STEP and STL (`cad/step`, `cad/stl`), EPR-DWG-001 Rev P2, concept media (hero, blueprint EPR-DWG-010 Rev P2, cutaway, exploded, flow, model.glb).
- Calculations re-run: EPR-CAL-001 v0.3 (`docs/04-calcs/sizing.py`, `results.csv`). Updated: EPR-PRC-001 v0.5, EPR-REQ-001 v0.5, `bom/bom.csv`, `bom/bom-notes.md`, `README.md` (links line, "Building the prototype" section, numbers), `project.yaml` (`design_state: constructable`, new evidence).

### Key results and requirements

- Force ratio, grip heights (1.89 to 0.86 m), peak pull (668 N, 334 N each), crank stop and eject force (470 N) are unchanged.
- Lowest safety factor still 1.13 (bush bearing); lid 1.61 (was 1.84, longer pin span); column at its access hole 2.49; eject arm 1.72.
- **R7 not met:** 200.0 kg against 190 kg (heaviest piece 45.0 kg, within 50 kg). The total now counts the guard and bolts (6.7 kg) that the concept left out.
- **R13 over the value-engineering target:** $520 estimated against the $500 target, USD 20 over.
- R2 and R4 at risk; R5, R1, R11 and R12 met on paper; R6 and R9 met by design review; R3, R8, R10 and R14 not verifiable at TRL 3.

### Proposed, awaiting Amish (register EPR-DEC-001)

The budget is not a decision: `budget_usd` stays $500 as a value-engineering target, with the savings worth trying in the register's Value engineering section (2026-10-01 wording pass).

1. R7: relax the total to 200 kg (recommended) or lighten.
2. Rest catch: hand release (recommended) or a foot pedal.
3. First co-design partner and region (no recommendation), plus the open questions carried over from the precis (bushes, wear liners, fill by volume, lime, design soil).

### Stale until regenerated on Amish's Mac

The photoreal renders (`media/render-*.png`, referenced by the README), `media/card.png`, `media/social-preview.png` and `cad/src/product_model.py` still show the concept's hinge knuckle, latch hook, eject fork, guide strap and plain link ends. `product_model.py` still imports from `model.py` (same names) but was not re-run.

### Safety concerns

Unchanged in kind: up to 173 kN in the linkage, 47 J kickback (now taken end on by the pawl), crushing at the mold, linkage and eject arm, a 27 kg lid, cement burns and silica dust. The rest catch must be in before the latch is opened; the build plan's safety stops cover this.

### Recommended next step

Amish reviews EPR-DDR-003 and decides open decisions 1 and 2. TRL 4 (building to the plan) stays on hold.

## Session 2026-09-26: sources strengthened

- "By country or region" in `README.md`: the Colombia and Latin America row had no citation. It now cites [Botti, *Frontiers of Architectural Research*, 2023](https://www.sciencedirect.com/science/article/pii/S2095263523000584), and the row was rewritten to what the paper supports (soil-cement blocks in Colombian projects by the 1940s; the CINVA-Ram designed at CINVA in Bogotá in 1956 and spread to Bolivia, Brazil, Peru and beyond). The unsupported phrase "living tradition of earth building" was removed.
- Kept and verified by fetching: UNEP *Global Status Report 2024/2025* (32 % energy, 34 % CO2), Chatham House 2018 (cement about 8 % of CO2), UN-Habitat housing page (3 billion people, 96,000 units a day), Auroville Earth Institute (49 against 643 kg CO2/m³), UN SDG Report 2024 Goal 11 (regional slum figures), 14.7.4 NMAC (300 psi for CEB), Botti 2023 (CINVA-Ram, What sparked the idea) and the OSE wiki (kept alongside Botti; hydraulic, $3,000 to $6,500 in materials).
- Inspiration unchanged; it already rests on a peer-reviewed paper.
- No controlled document changed. No budget change.

## Session 2026-09-25: recommendations accepted

On 2026-09-25 Amish wrote: "i accept all your recommendations, go with them across all repos." Every item with a recommendation is now **Decided by Amish, 2026-09-25: go with recommendation**, recorded in `docs/decisions/0002-recommendations-accepted.md` (EPR-DDR-002 v0.1). EPR-DDR-001 moves to v0.2 with the new statuses.

### Decisions applied and what changed

- 15 items decided: TRL 2 items 1 to 7 and 9, and TRL 3 items 10 to 16. Most were already in the model, so the geometry, STEP, STL and EPR-DWG-001 (Rev P1) are unchanged in substance; all were regenerated.
- Budget (item 14): `budget_usd` $450 to **$500**; R13 target $450 to $500. BOM unchanged at $488, so R13 goes from not met to met on paper ($12 margin).
- R5 wording (item 12): 500 N with the grip between 0.9 and 1.6 m, to 500 N or less per operator, grip 0.8 to 1.9 m, peak at 1.0 m or higher. With two operators (item 11) at 334 N each and the peak at 1,157 mm, R5 goes from not met to met on paper.
- R7 total (item 13): 140 kg to **190 kg**, piece limit 50 kg kept. At 187 kg, R7 goes from not met to met on paper (3.0 kg margin).
- Items 10, 15 and 16 (eject seesaw, weighed fill, linkage proposals): already in the model, BOM and precis; the word "proposal" was removed.
- Item 9: pitch and problem unchanged; its budget part is superseded by item 14.
- `docs/04-calcs/sizing.py` and EPR-CAL-001 to v0.2: the script checks the accepted R5 band and peak height and the 190 kg total, and reads the budget from `project.yaml`; results table updated.
- Controlled docs bumped with revision "Recommendations accepted by Amish (DDR-002)": EPR-PRB-001 0.3 to 0.4, EPR-PRC-001 0.3 to 0.4, EPR-REQ-001 0.3 to 0.4, EPR-CAL-001 0.1 to 0.2, EPR-DDR-001 0.1 to 0.2. `bom/bom-notes.md` and `README.md` updated for the $500 budget and the new status.
- Kit links switched to designmolecule.com: all docs PDFs, EPR-DWG-001 and all media regenerated; superseded PDFs removed from `docs/pdf/` where they still showed the old domain; `media/_views*` deleted. Hero, blueprint and exploded images checked by eye.
- README "What sparked the idea" rewritten around the CINVA-Ram (Raúl Ramírez, CINVA, Bogotá, 1956; patented 1958), cited to Botti, *Frontiers of Architectural Research*, 2023. The same source now closes the TRL 2 citation flag on the CINVA-Ram origin in EPR-PRB-001.

### Requirement status (EPR-CAL-001 v0.2)

| Status | Requirements |
| --- | --- |
| Not met | None |
| At risk | R2 (2.00 MPa only with two operators, a weighed fill and the assumed soil); R4 (296 against 300 blocks a day; item 16g, revisit when timed) |
| Not verifiable at TRL 3 | R3, R8, R10, R14 |
| Met on paper | R1, R5, R7 (3 kg margin), R11, R12, R13 ($12 margin) |
| Met (design review) | R6, R9 |

### Still awaiting Amish

1. **First co-design partner and region (item 8).** No recommendation; stays "Proposed, awaiting Amish".

### Cross-repo actions

None. EarthPress uses no shared component and no recommendation required another repo to change.

### TRL 4

TRL 4 remains on hold by Amish's instruction. Decided but on hold: confirming the stabilizer with partner soils (item 5), timing cycles for R4 (item 16g), and any build, block test, proof-load test or soil compaction measurement. `trl: 3`, `trl_target: 3`.

## Session 2026-09-25: TRL 3

### What was done

- `docs/decisions/0001-trl2-review-decisions.md` (EPR-DDR-001 v0.1): TRL 2 items 1 to 7 and 9 adopted as recommended for TRL 3 under Amish's 2026-09-25 instruction, open for his review; item 8 (partner) and seven new TRL 3 items (10 to 16) listed as open.
- `docs/04-calcs/01-sizing.md` (EPR-CAL-001 v0.1) with `docs/04-calcs/sizing.py` and `results.csv`: force, linkage kinematics, grip force and work against a soil compaction law, fill tolerance, structure at the design load, ejection, mass, output, material flow, carbon and cost, with a results table for R1 to R14. The script reads `cad/src/model.py` and `bom/bom.csv` and prints every quoted number.
- `cad/src/model.py`: parametric build123d model with the toggle kinematics (`toggle_state`, `knee_and_crank`, `lever_angle`) shared with the calculation. Parts: base on skids with lever bracket, press core (columns and base beam), mold box with belt, ribbed lid with hinge and latch, piston with slotted push rod, toggle links and pins, connecting link, lever hub, crank and T-handle, eject seesaw and end pawl, plus the sieve, test kit, gauge and context. Exports `cad/step/` and `cad/stl/` `earthpress-assembly`, `earthpress-set`, `earthpress-mold`, `earthpress-lid` and `earthpress-toggle`.
- `cad/src/sheets.py` and `cad/drawings/EPR-DWG-001.svg`, `.pdf`, `.png`: general arrangement, Rev P1, "CONCEPT, NOT FOR FABRICATION" and "PRELIMINARY, NOT FOR FABRICATION". The concept blueprint keeps EPR-DWG-010.
- `bom/bom.csv`: 13 lines, all priced with supplier types; new line 13 (linkage guard); `bom/bom-notes.md` totals against $450 and the recommended $500.
- `cad/src/concept_media.py` now builds from the model; every image in `media/` regenerated and checked by eye; the exploded-view lever offset was moved so it no longer crosses the legend; temporary `media/_views*` folders deleted.
- Docs updated to v0.3 with revision entries dated 2026-09-25: EPR-PRB-001, EPR-PRC-001, EPR-REQ-001. `project.yaml`: `trl: 3`, `trl_target: 3`, evidence listed; pitch, problem and `budget_usd` unchanged. `README.md`: TRL 3, numbers from EPR-CAL-001, links to the drawing, sizing note and DDR; the five required sections kept in order.

### Requirements (EPR-CAL-001)

Three met on paper, two met by design review, three not met, two at risk, four not verifiable at TRL 3.

| ID | Status | Value |
| --- | --- | --- |
| R5 | **Not met** | Peak pull 668 N (334 N each with two); grip 0.86 to 1.89 m. The 0.9 to 1.6 m band allows only 24.5° of arc with a 1.65 m grip radius |
| R7 | **Not met** | 187 kg against 140 kg; heaviest piece 36.6 kg (limit 50 kg); fits a 1.5 m bed |
| R13 | **Not met** | $488 against $450 (recommended $500, awaiting Amish) |
| R2 | At risk | 2.00 MPa with two operators and a fill of 0 to +2.7 %; one operator at 500 N stalls at 0.53 MPa; peak 571 to 809 N over the soil range |
| R4 | At risk | 296 blocks a day on an assumed 85 s cycle |
| R3, R8, R10, R14 | Not verifiable at TRL 3 | Need block tests, wear data or an outside review; fatigue range 89 MPa against 243 MPa allowed |
| R1, R11, R12 | Met on paper | Height 90.0 mm at the stop; CO2 7.6 % of fired brick; lid and latch checked at 173 kN, end pawl, guard |
| R6, R9 | Met (design review) | Bought turned parts only; kit defined |

Other key numbers: 81.2 kN for 2 MPa; force ratio 173:1 at the stop; lever arc 59.2°; compaction work 494 J (353 to 705 J); design load 173 kN (1,000 N at the grip); lowest safety factor 1.13 (bush bearing); kickback 47 J; eject 4.83 kN at 468 N on the grip; 1,683 blocks and 556 kg of cement for a small house.

TRL 2 figures corrected: press mass 123 to 187 kg; cost $403 to $488; compaction work 0.6 to 1.2 kJ to 0.35 to 0.71 kJ; output about 300 to 296 blocks a day; lever 1.5 to 1.7 m; the 22 mm lid (275 MPa at 2 MPa, above yield) replaced by a ribbed lid; ejection by continuing the stroke replaced, because a toggle ending near straight cannot lift the piston another 90 mm.

### Decisions recorded (EPR-DDR-001)

Adopted as recommended for TRL 3 under Amish's 2026-09-25 instruction, now decided by Amish, 2026-09-25: go with recommendation (EPR-DDR-002): toggle mechanism (item 1); longer lever arc with a higher end grip (item 2, met in intent with a low pivot, since the 800 mm pivot and 100° arc would put the grip below the ground); 290 x 140 x 90 mm block (3); 2 MPa (4); 5 % cement with lime for clay soils (5); 12 mm base plate and bolted mold (6); field tests only (7); no change to budget, pitch or problem (9).

### Items then awaiting Amish (all but item 8 now decided, EPR-DDR-002)

1. **First co-design partner and region (item 8).** No recommendation.
2. **Ejection (item 10).** Recommendation: separate eject seesaw with the lever in a second socket and a lost-motion slot (in the model). **Decided by Amish, 2026-09-25: go with recommendation.**
3. **Two operators (item 11).** Recommendation: two people on a T-handle (in the model). **Decided by Amish, 2026-09-25: go with recommendation.**
4. **R5 wording (item 12).** Recommendation: 500 N or less per operator; grip 0.8 to 1.9 m with the peak force at 1.0 m or higher. **Decided by Amish, 2026-09-25: go with recommendation.**
5. **R7 total (item 13).** Recommendation: relax the total to 190 kg, keep the 50 kg piece limit. **Decided by Amish, 2026-09-25: go with recommendation.**
6. **Budget (item 14).** Recommendation: raise `budget_usd` to $500 ($488 now). Not applied. **Decided by Amish, 2026-09-25: go with recommendation.**
7. **Fill control (item 15).** Weigh every fill on a 10 kg scale to about +1.3 % ± 100 g. **Decided by Amish, 2026-09-25: go with recommendation.**
8. **Engineering proposals (item 16).** Linkage geometry and 940 mm rim, crank stop at 6° (173 kN design load), ribbed lid, end pawl, linkage guard, hardened steel bushes, and R4 at 296 blocks a day. **Decided by Amish, 2026-09-25: go with recommendation.**

### Cross-repo notes

EarthPress depends on none of the shared components in this batch (FieldNode, CellGuard, MotionCore, ThermaCart, TwinKit, CalRig) or SwapCell. No other repo was read or changed.

### Safety concerns

- Up to 173 kN in the linkage if two people pull hard at the stop; crushing in the mold, linkage, crank scissor and eject fork. The guard is not modeled.
- Lever kickback of about 47 J if released at the end of the stroke; the end pawl is a paper design.
- The lid weighs 26 kg and is lifted every cycle (about 127 N at the latch end); it must never be opened with the lever off its rest stop.
- The soil law is an assumption: a softer soil raises the peak pull to 809 N, and operators may then hang on the lever.
- Cement burns, silica dust from dry sieving, 7.6 kg blocks handled about 300 times a day, and uncertified blocks for structural use are unchanged from TRL 2.

### Other notes

- No TRL 4 material exists in the repo: no test plans or reports, build procedures, cut lists or purchasing lists. `build-log/README.md` is the scaffold stub and was not touched.
- Citations: the TRL 2 note flags the CINVA-Ram origin (Colombia, 1950s) as stated without a link. WebFetch could not reach the Wikipedia CINVA Ram page (the domain is cache-only for this tool), and the Wikipedia compressed earth block page does not mention it, so the flag stays. WebSearch was not used (quota exhausted).
- The linkage geometry came from a numerical design search (minimum peak grip force with the grip between 0.8 and 1.9 m); the search script is not in the repo, and `sizing.py` checks the chosen geometry.
- The kit's cutaway cuts at the mean Y of the parts; the press is centered on Y = 0 and the sieve, kit, gauge and blocks are excluded, so the cut passes through the piston axis without shifting the model.
- The soil compaction law (tenfold over the last 14 mm) is the largest single uncertainty in R2 and R5.
- `render.py --check` and `render.py` pass; PDFs are in `docs/pdf/`.

### Recommended next step

Review EPR-DDR-001, in particular the two-person lever (item 11), the R5 and R7 rewording (items 12 and 13) and the budget (item 14), and choose the first partner (item 8). TRL 4 is on hold by Amish's instruction. For reference only, TRL 4 would need: a bench build of the press; a lab test report (TST, `environment: lab`) covering the soil compaction curve with partner soil, grip force through the stroke with one and two operators, fill-mass sensitivity, lid and latch proof load at 1.5 times the block force, ejection force, cycle time and block strength after curing; and build-log entries. None of this has been started.

## Session 2026-09-25: /populate to a strong TRL 2

### What was done

- `docs/01-problem.md` (EPR-PRB-001 v0.2): why it matters (cited), users and context, constraints, out of scope, prior work with sources (CINVA-Ram, Auroville Earth Institute, Open Source Ecology CEB Press, 14.7.4 NMAC, ISSB presses), open questions; co-design checklist kept.
- `docs/03-requirements.md` (EPR-REQ-001 v0.2): 14 measurable requirements (R1 to R14) with targets, verification and a concept status column, plus a list of requirements not met or at risk.
- `docs/02-concept.md` (EPR-PRC-001 v0.2): how it works in six steps, numbered components, first-order numbers with assumptions, key design choices, safety section, open questions.
- `cad/src/concept_media.py`: massing model of the press (frame on skids, mold box, lid, piston, toggle, lever and crank, ejection stop and catch) with the soil sieve, test kit, block gauge, a block stack and loose soil fill as context; 1.75 m scale figure.
- `media/`: `hero.png`, `concept-blueprint.png`, `.pdf` and `.svg`, `cutaway.png` (mold, fill, piston and toggle), `exploded.png` (callouts 1 to 10 match the BOM), `flow.png` (material flow per 100 blocks, estimates), `model.glb` and `viewer.html`. Temporary `media/_views*` folders removed.
- `bom/bom.csv`: 12 lines with indicative USD costs, rows 1 to 10 numbered to match the exploded view; `bom/bom-notes.md` updated.
- `README.md`: hero image and links line after the intro; Concept rationale, Burning platform, Where it could be used (by industry, by country or region), What sparked the idea, Problem, Concept, Key components and Safety expanded with cited figures.
- `docs/pdf/`: branded PDFs of the three controlled documents.

### Key results (estimates, to be checked at TRL 3)

| Quantity | Estimate | Requirement |
| --- | --- | --- |
| Block | 290 x 140 x 90 mm, about 6.9 kg dry | R1 |
| Force for 2 MPa | about 81 kN | R2 |
| Force ratio | lever about 19:1 times toggle about 9:1 (within about 3° of straight) | R2 force met on paper |
| Compaction work versus one operator | about 0.6 to 1.2 kJ needed, about 0.65 kJ available over a 50° arc | **R2 at risk** |
| Lever grip height | about 1.36 m at start, about 0.3 m at end | **R5 at risk** |
| Output | about 300 blocks per day, crew of four (about 9 m² of wall) | R4 met on paper |
| Press mass | about 123 kg total; frame about 61 kg | **R7 not met** (50 kg per piece) |
| Cement | about 0.33 kg per block; about 560 kg for a 50 m² wall | R10 target 5 % |
| Embodied CO2, 7.1 m³ of walling | about 0.35 t CSEB against about 4.6 t fired brick (about 8 %) | R11 met on paper |
| Parts cost | about $403 | R13 met ($450 budget) |

Requirements not met or at risk:

- **R7 not met:** the frame is about 61 kg against a 50 kg single-piece limit.
- **R2 at risk:** the force ratio can reach 2 MPa, but one operator may not deliver enough work over the modeled 50° lever arc.
- **R5 at risk:** the grip ends about 0.3 m above ground at the point of highest force.
- **R3, R8 and R10 cannot be shown at TRL 2**; block strength depends on soil, mix and curing and needs block tests (TRL 4).
- R12 and R14 are addressed in concept only.

### Proposed, awaiting Amish (items 1 to 7 and 9 now decided by Amish, 2026-09-25: go with recommendation, EPR-DDR-002; item 8 still awaiting Amish)

1. **Mechanism.** Option A: bottom piston with a toggle and one lever for press and eject (CINVA-Ram pattern). Option B: the same frame with a 20 t hydraulic bottle jack (reaches 4 MPa easily, adds a bought hydraulic part). Option C: screw press (slow). Recommendation: A, with B documented later as a variant.
2. **Lever layout.** Raise the lever pivot to about 800 mm for a 100° arc, to fix R2 and R5, rather than keeping the low pivot in the model. Recommendation: raise it at TRL 3.
3. **Block size.** Flat 290 x 140 x 90 mm (Auroville module), 300 x 150 x 100 mm, or an interlocking block. Recommendation: 290 x 140 x 90 mm, with interlocking inserts as a later option.
4. **Compaction target.** 2 MPa (manual, one or two operators) or 4 MPa (needs about 162 kN). Recommendation: 2 MPa.
5. **Stabilizer default.** 5 % cement by dry mass, with lime for clay-rich soils. Recommendation: as stated, confirmed with partner soils.
6. **Meeting R7.** Thinner 12 mm base plate and a bolted mold, or a two-part bolted frame, or relaxing R7 to 65 kg. Recommendation: thinner base plate plus bolted mold.
7. **Soil test kit scope.** Field tests only, or add a small hand-operated block crusher for strength checks. Recommendation: field tests only at TRL 3.
8. **First partner and region** for co-design (for example an earth-building NGO in East Africa or India).
9. **Budget.** No change proposed; about $403 is within $450. `project.yaml` pitch and problem are unchanged because the figures found support them.

### Safety concerns

- About 81 kN at the piston: crushing of hands in the mold or linkage; lever kickback if the grip slips or a pin fails; lid or latch failure under load.
- Portland cement burns to skin and eyes; respirable crystalline silica from sieving dry soil.
- Manual handling: 7 kg blocks repeated hundreds of times a day, and a 123 kg press.
- Blocks are uncertified; structural and seismic use needs an engineer and tests under local code.
- Welding and grinding hazards while building the press.

### Problems and notes

- The massing model is proportional, not kinematic: the modeled crank is about 60 mm and the toggle links about 185 to 200 mm, while the precis uses about 80 mm and about 190 mm. The TRL 3 model should set these from the linkage calculation.
- WebSearch was unavailable in this session (session search budget used up), so sources were verified by fetching the primary pages directly. No figure was used that could not be confirmed on its source page. The CINVA-Ram origin (Colombia, 1950s) is stated without a link.
- The legacy `cad/src/model.py` placeholder is untouched (TRL 3 work).

### Recommended next step

Review this note and the media, then decide items 1 to 4 and 6. If approved, run `/advance-trl3` to size the linkage and lever layout by calculation (force ratio and work over the stroke), check the lid, latch, pins and links, and build the parametric model and drawing sheet.

## Session 2026-09-26: product appearance model and photoreal renders

Amish chose this repo for the first batch of product renders on 2026-09-26.

### What was added

`cad/src/product_model.py` exposes `product_parts()` (54 parts: 24 shell, 9 internal, 17 accessory, 4 context), `TITLE` and `RENDER_VIEWS` (hero with the operator, exploded, and a detail view of the toggle linkage, connecting link and lever hub under the mold box, without the lever pipe, operator or ground). It imports PARAMS and the kinematics (`geometry()`, `theta_start()`, `toggle_state()`, `knee_and_crank()`) and the geometry helpers from `cad/src/model.py`; every main dimension and interface is as model.py. It adds:

- Base skids and cross tubes as rounded 60 and 50 mm hollow sections with rubber end caps; filleted base plate, lever bracket plates and rest stop with a rubber pad.
- UPN 80 columns, base beam, rounded toggle base lugs and column feet with eight M12 bolt heads; a yellow pinch-point label on the front column.
- Teal mold box with a rounded belt, flanges, guide strap, hinge base and latch keeper; a bright ground rim; eight M16 bolt heads on the column webs; a raised EARTHPRESS nameplate on the belt.
- Lid with filleted plate and ribs, hinge knuckle, latch hook with a rubber grip, bright hinge and latch pins with circlips.
- Piston and slotted push rod in bright steel, with the foot pin.
- Round-ended toggle links and connecting link in safety orange; 35 mm pins with circlips, bush flanges and brass grease nipples.
- Lever hub, round-ended crank plates and socket; crank pin and circlips. The 2 in lever pipe and T-handle as a removable accessory, with ringed rubber grips and end caps.
- Eject seesaw with round-ended fork plates, posts, pivot pin and socket; the end-of-stroke pawl.
- Soil sieve with a timber frame, wire mesh and prop; soil test kit crate with hand holes and vents, a shrinkage box, two clear 1 L jars showing settled sand, silt and clay layers, and a laminated chart; block gauge with a grip.
- Context: a compact patch of compacted earth, the stack of 32 finished blocks, the loose soil in the mold, and the shared clay mannequin (1.75 m, push pose) with both hands on the T-handle grips and feet on the ground.

`README.md` now shows `media/render-hero.png` and links `media/render-exploded.png`; the orchestrator produces both files. Matplotlib self-check previews (clear parts left out) are in `/tmp/earthpress-prod/`.

### Differences from model.py (Proposed, awaiting Amish)

1. **Pose.** The press is shown at 85 % of the compaction stroke (toggle about 9.5° from vertical, T-handle at about 1.21 m) instead of at the start of the stroke, so the operator's push reads. The pose uses model.py's own kinematics; no dimension changes. Recommendation: keep this pose for renders only.
2. **Link ends.** Toggle links, the connecting link, crank plates and eject fork plates extend half their width past the pin centres with round ends; model.py stops each bar at the pin centres, which leaves no metal round the pins. Recommendation: adopt round ends in model.py at the next model revision.
3. **Added visible details not in the BOM:** the nameplate, the pinch-point label, rubber tube end caps, the rest stop pad and the latch hook grip. Recommendation: add labels and caps to BOM line 11 (hardware and finish) if Amish accepts them.
4. **One operator.** The mannequin is a single person, while EPR-CAL-001 needs two people on the T-handle (668 N peak pull). Recommendation: keep one figure for a clean hero, and state two operators in the caption; or add a second mannequin on the other half of the T-handle.
5. **Placement of the kit.** The soil sieve moves from about (1150, 750) to (250, 690) mm, behind the press, and the test kit 50 mm toward the press, to keep the ground patch compact. The sieve mesh is drawn at a 30 mm pitch, not 5 mm. Recommendation: accept for renders.
6. **Colours** differ from the concept media: graphite frame, teal mold and lid, orange linkage, black lever, grey eject lever. Recommendation: accept as the product palette.
7. **Linkage guard (BOM 13)** is not shown, as in model.py, so the toggle can be seen. Recommendation: show it as expanded metal in a later render once its shape is drawn.

### TRL

This is an appearance model only. No tolerances, fabrication detail, build or test work were added. `trl: 3`, `trl_target: 3`; TRL 4 remains on hold.

## Session 2026-09-27: kit 1.5.0 and image quality

- Kit 1.5.0 synced: STANDARDS v1.5 (sections 12 to 15: product renders, storefront images and image quality, public release, authorship and signing), `.kit/cards.py`, `.kit/image_qc.py`, `.kit/release_gate.py`, issue templates, and the `/render-product` and `/release` commands. `CLAUDE.md` now matches `.kit/CLAUDE.md`.
- Every `media/render-*.png` recaptioned from its original render with the new layout: the title, concept label and repository sit in a band above the render and the view note in a band below it, each line wrapped to the image width, so no text overlaps other text or the render or runs off the image. `media/card.png` and `media/social-preview.png` regenerated with the same rules.
- `python .kit/image_qc.py` and `python .kit/release_gate.py` pass. trl stays 3.

## Session 2026-10-02: open decisions decided

Amish, 2026-10-02: "i approve your recommendations for all 555 open decisions." This approves the recommendation written for every open decision in the design decisions register (EPR-DEC-001). trl stays 3; nothing was built, bought or tested, and TRL 4 remains on hold.

### Decisions recorded (8)

| Register item | Decision |
| --- | --- |
| 1 | R7 total 200 kg including the guard and bolts; 50 kg piece limit kept (EPR-DDR-003 A1 accepted) |
| 2 | Hand release of the rest catch for the prototype; the catch is in before the latch is opened; foot pedal only if timed cycles show a cost (EPR-DDR-003 A3 accepted) |
| 3 | Partner that already trains builders in stabilized earth blocks; first candidate to approach, the Auroville Earth Institute |
| 4 | Case-hardened steel bushes with grease nipples kept; felt or rubber dust seals added at the bush faces |
| 5 | Plain 12 mm mold walls for the prototype, wear measured against R8; liners only if needed |
| 6 | Weigh every fill; calibrated scoop only for a soil with measured scatter inside the 0 to 2.7 % window |
| 7 | Cement default; lime a documented option with its own chart and longer curing; no press change |
| 8 | Operating chart on the softer soil (809 N, 405 N per operator) until partner soils are measured |

All 8 moved to Decisions made in EPR-DEC-001, dated 2026-10-02; the Open decisions section now reads "None."

### Documents changed

- `docs/06-design-decisions.md` (EPR-DEC-001 v0.3): items 1 to 8 moved to Decisions made; Open decisions reads "None"; the lighter-press saving in Value engineering reworded now that decision 1 is made
- `docs/decisions/0003-design-for-construction.md` (EPR-DDR-003 v0.3): A1 and A3 recorded as accepted (status kept Draft; Table 1 still open for review at that point, see below); R7 consequence updated
- `docs/03-requirements.md` (EPR-REQ-001 v0.7): R7 relaxed to 200 kg including guard and bolts, now met on paper; R5 status gives the softer design soil; summary updated
- `docs/04-calcs/01-sizing.md` (EPR-CAL-001 v0.5): R7 text and results row against 200 kg; softer design soil noted under R5
- `docs/02-concept.md` (EPR-PRC-001 v0.7): R7 status; weighed fill and scoop rule; design soil; bush dust seals; lime option; plain mold walls
- `docs/01-problem.md` (EPR-PRB-001 v0.5): partner rule and first candidate; design soil and lime; press mass
- `bom/bom-notes.md`: dust seals at the bush faces and plain mold walls noted
- `README.md`: R7 status
- `docs/decisions/0001-trl2-review-decisions.md` (EPR-DDR-001 v0.3): item 8 ("Proposed, awaiting Amish") recorded as decided
- `docs/decisions/0002-recommendations-accepted.md` (EPR-DDR-002 v0.2): item 8 recorded as decided
- PDFs regenerated with `python3 .kit/render.py`; superseded versions removed.

Note: the register had no open item for accepting the design-for-construction changes P1 to P15 as a whole (EPR-DDR-003, Table 1), so this approval did not cover them. Amish accepted them later on 2026-10-02 (see the next session).

### Follow-up actions to carry approved decisions into the design

The model, BOM quantities and prices, calculations and pictures were not changed in this session. These actions carry the approved decisions into them:

1. Decision 1 (calculations): Re-run `docs/04-calcs/sizing.py` with the R7 total at 200 kg including the guard and bolts so its R7 line and `results.csv` show met on paper.
2. Decision 4 (model, BOM): Add felt or rubber dust seals at the bush faces: a BOM line or an addition to line 5 with a price, and the seal faces in the model and the link making sketches if they change the stack-up.
3. Decision 4 (drawings, build plan pictures): Show the dust seals in the toggle linkage joint pictures and making sketches once modelled.
4. Decision 6 and 8 (calculations, documents): Write the operating chart for the softer design soil (809 N, 405 N per operator) and the scoop calibration rule into the test kit procedure; recompute per soil once partner soils are measured.
5. Decision 7 (documents): Add a lime mix chart and its curing period to the soil test kit procedure.
6. Decision 5 (test plan): Measure mold wall wear at TRL 4 against R8; design bolt-on liners only if the rate would not last 50,000 sandy blocks.
7. Decision 3 (documents): Approach the first candidate partner (the Auroville Earth Institute); nothing is agreed yet.

### Points found in the review

Raised when the recommendations were written (2026-10-01) and kept here so they are not lost:

- Item 1 does not compare like with like: the 190 kg limit was set against a 187 kg figure that left out the guard and bolts (6.7 kg), so the 200 kg total is about 6 kg of real growth plus 6.7 kg newly counted.
- Item 4 overlaps a decision already made: case-hardened steel bushes were accepted on 2026-09-25 (EPR-DDR-002, item 16f).
- Item 7 overlaps a decision already made: 'lime for clay-rich soils' was accepted with the stabilizer choice on 2026-09-25 (EPR-DDR-001, item 5); only the chart and curing details are open.
- The seven appearance items from REVIEW.md 2026-09-26 are not in the register. Two touch what the renders claim: item 4 shows one operator although the press needs two (668 N peak), and item 7 leaves the linkage guard out of the renders; both should be resolved before the renders are public.
- Item 6 is already decided for now (weighed fill, EPR-DDR-002 item 15); the open part is only the future scoop rule.

## Session 2026-10-02: design-for-construction changes accepted

Amish, 2026-10-02: "APPROVED: Design-for-construction changes in 10 repos (CityTwin, CoolShade, PalletPilot, Heliolite, PotholeLog, EarthPress, ReadyKit, CellCheck, CargoMule and ThermaCart)". This accepts the design-for-construction changes P1 to P15 in Table 1 of EPR-DDR-003, which were left open for his review when the open decisions were decided earlier the same day. No other item is decided by it. trl stays 3; no build or test work was done, and the model, BOM, calculations and pictures are unchanged.

### Documents changed

- `docs/decisions/0003-design-for-construction.md` (EPR-DDR-003 v0.4, status Draft): status line now "accepted" with Amish's words.
- `docs/06-design-decisions.md` (EPR-DEC-001 v0.4): Decisions made row added, dated 2026-10-02; the 2026-10-01 row no longer calls the changes open for review.
- `docs/05-build-plan.md` (EPR-BLD-001 v0.3): section 2 says EPR-DDR-003 is accepted.
- PDFs regenerated.

### Recommended next step

No change: the follow-up actions of the previous session stand. TRL 4 remains on hold by Amish's instruction.

## Session 2026-10-02: approved follow-ups carried out

Authority: Amish, 2026-10-02, approved every follow-up action from the open-decision sign-off. `trl` and `trl_target` stay at 3; `budget_usd` is unchanged at 500. No commit or push.

### Follow-ups

1. Decision 1, R7 at 200 kg: done. `docs/04-calcs/sizing.py` re-run: steel 200.0 kg (199.991 kg) plus about 5 g of felt dust seals is 199.996 kg, so R7 is met on paper with a 4 g margin; `results.csv` updated. The margin is too small to mean anything; the weighed prototype decides.
2. Decision 4, dust seals in the model and BOM: done. `cad/src/model.py` now has eight 2 mm felt or rubber washers (50 mm outside, 35.5 mm bore) on the outer link faces at the base, knee and upper pins; pins already ended 4 mm past the links, which leaves room for the seal and a 1.5 mm circlip, so no part of the stack-up changed. Model checks: 52 of 52 pass (new: seal contacts, circlip room, seal clearance from the column webs). BOM line 5 goes from USD 91 to USD 94 (eight washers at about USD 0.35, rounded to USD 3); STEP and STL regenerated.
3. Decision 4, drawings and pictures: done. EPR-DWG-001 now Rev P3; the toggle link making sketch (EPR-DWG-107) notes the seals; joint pictures for the base pin, knee and upper pin, the overview and assembly steps 5 to 7 show them; concept media regenerated.
4. Decisions 6 and 8, operating chart and scoop rule: done. New build plan section 3.15 (soil test kit procedure) carries the operating chart for the softer design soil and the scoop rule; `sizing.py` section 4b computes them. Finding: on the softer soil the good fill window narrows to 0 to +2.0 % (from 0 to +2.7 %), so the weighing target for it is +1.0 % (7.72 kg) give or take 75 g, not +1.3 %. Peak pull 809 N (405 N each) at nominal fill and 498 N each at +2.0 %.
5. Decision 7, lime chart: done, as starting values to be confirmed by strength tests: 8 % hydrated lime (51 kg per 100 blocks against 33 kg of cement), about 8 weeks damp curing against about 4 (`sizing.py` section 4c; build plan Table 3). The 8 % and 8 weeks are my assumptions, not sourced figures.
6. Decision 5, mold wall wear measurement: not done, TRL 4 test plan work.
7. Decision 3, approach the Auroville Earth Institute: not done, outreach by Amish.

### Requirement status changes

- R7: met on paper (was not met against 190 kg until 2026-10-02; the calculation now confirms it): 199.996 kg.
- R13: stays over the target, now by USD 23 (USD 523 against USD 500). Value-engineering target: USD 500. Estimated cost of the constructable design: USD 523 (USD 23 over the target).
- No other status changed.

### Documents changed and new versions

EPR-CAL-001 v0.6; EPR-REQ-001 v0.8; EPR-PRC-001 v0.8; EPR-BLD-001 v0.4; EPR-DEC-001 v0.5. Also `README.md`, `bom/bom.csv`, `bom/bom-notes.md`, `docs/04-calcs/sizing.py` and `results.csv`, `cad/src/model.py`, `sheets.py`, `build_plan_media.py`, `concept_media.py`, `product_model.py`.

### Render scenes

`cad/src/product_model.py` was out of date (it still used parameters from before the constructable design and failed to run). It now takes every steel part from `cad/src/model.py` itself (round link ends, tapped flanges, access holes, catch, guard, bolts, seals) and adds only paint, rubber, felt, circlips, grease nipples, grips, the sieve, test kit, blocks and the mannequin. The decorative extras of 2026-09-26 that no longer match (nameplate, pinch-point label, rest stop pad, latch hook grip, mold rim band, bush flanges) are dropped; the guard is now shown. Scenes exported to `/home/claude/renders/earthpress` for the views hero, exploded and detail, with `earthpress__jobs.json`. Photoreal images, `card.png` and `social-preview.png` are to be made on Amish's Mac.

### Cross-repo actions

None for other repos.

### Decisions proposed and awaiting Amish

None new. The lime values (8 %, 8 weeks) in Table 3 of the build plan are starting figures to confirm at TRL 4.

## 2026-10-02: photoreal renders redone on the constructable design

Rendered with Blender Cycles on Amish's Mac from the updated appearance model; captioned with `.kit/photo_caption.py`; `media/card.png` and `media/social-preview.png` regenerated with `.kit/cards.py`. Views: hero, exploded, detail. image_qc passes. Appearance deviations are those logged above as proposed, awaiting Amish.

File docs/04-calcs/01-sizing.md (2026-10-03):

---
doc_id: EPR-CAL-001
title: EarthPress sizing calculations
project: EarthPress
doc_type: Calculation note
version: "0.6"
status: Draft
date: '2026-10-02'
author: Amish Chadha
license: CERN-OHL-S-2.0
revisions:
- version: "0.1"
  date: '2026-09-25'
  author: Amish Chadha
  change: First TRL 3 sizing note (force, linkage kinematics, grip force and work, fill tolerance, structure at the design load, ejection, mass, output, material flow, carbon, cost) against every requirement in EPR-REQ-001
- version: "0.2"
  date: '2026-09-25'
  author: Amish Chadha
  change: "Recommendations accepted by Amish (DDR-002). R5, R7 and R13 checked against the accepted targets (500 N per operator, grip 0.8 to 1.9 m with the peak at 1.0 m or higher; 190 kg total; $500 budget); script reads the budget from project.yaml"
- version: "0.3"
  date: '2026-10-01'
  author: Amish Chadha
  change: "Constructable design (EPR-DDR-003): lid span 420 mm between the hinge and latch pins, link net section at the 41 mm bush, column access holes, eject arm, mass with guard and bolts (200 kg, R7 not met), cost $520 (R13 not met)"
- version: "0.4"
  date: '2026-10-01'
  author: Amish Chadha
  change: Budget treated as a value-engineering target
- version: "0.5"
  date: '2026-10-02'
  author: Amish Chadha
  change: "R7 against the 200 kg total set on 2026-10-02 (met on paper); softer design soil for the operating chart noted under R5; sizing.py still to be re-run"
- version: "0.6"
  date: '2026-10-02'
  author: Amish Chadha
  change: 'sizing.py re-run: R7 met at 200 kg (199.996 kg with the dust seals), BOM USD 523 with dust seals (R13 over by USD 23); operating chart for the softer design soil and the scoop rule added (section 5b)'
---

# EarthPress sizing calculations

On paper the press reaches 2 MPa on the 290 x 140 x 90 mm block, but only with **two people on the lever** and a **weighed fill**. The toggle and 1.7 m lever give a force ratio of 173:1 at the stop, and the peak pull under the base soil assumption is **668 N**, which comes about 3 mm before the end of the stroke. One operator pulling 500 N stalls at about 0.5 MPa, so the press is a two-person machine, as Amish decided on 2026-09-25 (EPR-DDR-002). Against the targets he accepted that day, **R5** is met on paper (334 N per operator, grip 0.86 to 1.89 m, peak at 1.16 m). Since the design was made buildable on 2026-10-01 (EPR-DDR-003, v0.3 of this note), R7 was not met (200 kg against 190 kg; no piece over 45 kg, so the 50 kg piece limit is met) until Amish set the total at 200 kg including the guard and bolts on 2026-10-02, so it is now met on paper (199.996 kg, a 4 g margin), and **R13 is over its value-engineering target** (estimated $523 against a $500 target, USD 23 over, after the dust seals decided on 2026-10-02 added $3); the cost savings worth trying are in the design decisions register (EPR-DEC-001). R2 and R4 are **at risk**; R3, R8, R10 and R14 cannot be verified at TRL 3.

The calculation corrects four TRL 2 figures and one TRL 2 mechanism. The press mass rises from about 123 kg to 187 kg, the cost from about $403 to $488 and the compaction work falls from 0.6 to 1.2 kJ to about 0.35 to 0.71 kJ (0.49 kJ base). The 22 mm lid would reach yield at 2 MPa and is now a ribbed lid. The TRL 2 concept ejected the block by pulling the lever on past the compaction point, which a toggle ending near straight cannot do; ejection now uses a separate seesaw lever and a lost-motion slot in the push rod.

Every number here is printed by `docs/04-calcs/sizing.py` (run from the repo root: `python docs/04-calcs/sizing.py`), which also writes `docs/04-calcs/results.csv`. The script reads the geometry from `cad/src/model.py` and the costs from `bom/bom.csv`. All values are first-principles estimates; nothing is measured.

## 1. Assumptions

*Table 1. Inputs. All are assumptions for a paper design.*

| Input | Value | Basis |
| --- | --- | --- |
| Block | 290 x 140 x 90 mm; loose fill 150 mm deep | EPR-DDR-001 item 3 |
| Target pressure | 2.0 MPa at the end of the stroke | EPR-DDR-001 item 4, R2 |
| Dry block density | 1,900 kg/m³ | TRL 2 assumption |
| Stabilizer and water | 5 % cement on dry soil, 10 % water on dry mix | EPR-DDR-001 item 5 |
| Soil compaction law | Pressure rises tenfold over the last 14 mm of the stroke (exponential); range 10 to 20 mm | Assumed; to be measured with partner soil |
| Operators | 500 N for one person (R5 limit); 1,000 N for two on the T-handle, also the abuse case | Assumed |
| Working grip band | 0.8 to 1.9 m above ground, peak force at 1.0 m or higher | R5 as accepted by Amish, EPR-DDR-002 |
| Steel | Yield 250 MPa (plate and sections), 240 MPa (A53 grade B pipe), 370 MPa (C45 pins); E = 200 GPa | Lower-bound catalog values |
| Bush bearing pressure | 100 MPa allowable, hardened steel, greased, slow oscillation | Assumed |
| Lateral pressure in the mold | 0.5 x vertical during pressing; 0.1 MPa residual after unloading, friction 0.6 | Assumed |
| Soil rebound at 2 MPa | 1.0 mm | Assumed |
| Bolts | M16 8.8, 60.3 kN each in single shear through the thread | 0.6 x 800 x 157 / 1.25 |
| Fatigue | FAT 71 welded detail, 243 MPa range at 50,000 cycles | 71 x (2 x 10⁶ / 5 x 10⁴)^(1/3) |
| Cycle | 85 s per block (Table 6); 7 working hours per 8 h day | Assumed, to be timed |
| Soil preparation | 15 % oversize; sieving 400 kg/h and mixing 600 kg/h per person; 3 % rejects remixed | Assumed |
| Carbon | 49 kg CO2/m³ for 5 % CSEB, 643 kg CO2/m³ for fired brick | [Auroville Earth Institute](https://www.earth-auroville.com/compressed_stabilised_earth_block_en.php) |
| Steel price | About $1.30/kg | Indicative, TRL 2 basis |

## 2. Block and force (R1, R2)

The block face is 0.0406 m², so **2 MPa needs 81.2 kN** (4 MPa would need 162.4 kN). The block holds 3.65 L and weighs 6.94 kg dry and 7.64 kg moist at the press, with 0.33 kg of cement. A 150 mm loose fill compacts to 90 mm, a ratio of 1.67, which implies a loose dry density of about 1,140 kg/m³ in the mold.

## 3. Linkage and lever (R2, R5)

The mechanism is a bottom piston driven by a symmetric toggle (two 245 mm links), whose knee is pushed by a 420 mm connecting link from a 107 mm crank on the lever hub. The geometry in `cad/src/model.py` came from a design search that minimized the peak grip force while keeping the grip between 0.8 and 1.9 m; the script checks it.

*Table 2. Kinematics.*

| Quantity | Value |
| --- | --- |
| Toggle angle from vertical, start to stop | 29.3° to 6.0° |
| Piston stroke | 60.0 mm |
| Base pin and upper pin heights at the stop | 298 mm and 785 mm (mold rim at 940 mm) |
| Lever pivot | x = -468 mm, z = 266 mm; grip radius 1,650 mm |
| Lever angle, start to stop | 99.6° to 158.8° from horizontal (+X), an arc of **59.2°** |
| Grip path | 1.71 m |
| Grip height, start to stop | 1,893 mm to 863 mm |
| Force ratio at 30 mm and at the stop | 20.0:1 and **173:1**; it rises monotonically to the stop |

**The original R5 band could not hold a useful arc.** A grip 1.65 m from the pivot can stay between 0.9 and 1.6 m for only 24.5° of arc. The TRL 2 recommendation to raise the pivot to about 800 mm for a 100° arc does not work with a lever of this length: a symmetric 100° arc would take the grip to -464 mm, below the ground. The design therefore keeps a low pivot and starts the lever nearly upright, which gives 59° of arc with the grip between 0.86 and 1.89 m. This meets the intent of EPR-DDR-001 item 2 (a longer arc and a higher grip at the end) but not its wording, and it did not meet the original 0.9 to 1.6 m R5 band. Amish accepted the reworded R5 on 2026-09-25 (grip 0.8 to 1.9 m with the peak force at 1.0 m or higher; EPR-DDR-002), and the design meets it: the grip stays inside the band and the peak comes at 1,157 mm.

## 4. Grip force and work (R2, R5)

*Table 3. Grip force through the stroke, base soil (14 mm per decade).*

| Travel (mm) | Piston force (kN) | Force ratio | Grip force (N) | Grip height (mm) |
| --- | --- | --- | --- | --- |
| 0 | 0.00 | 14.8 | 0 | 1,893 |
| 30 | 0.59 | 20.0 | 29 | 1,735 |
| 40 | 3.04 | 25.0 | 122 | 1,621 |
| 50 | 15.7 | 37.5 | 417 | 1,429 |
| 55 | 35.7 | 56.5 | 632 | 1,257 |
| 57 | 49.8 | 74.5 | **668** | 1,150 |
| 59 | 68.7 | 115.8 | 593 | 994 |
| 60 | 81.2 | 173.0 | 469 | 863 |

- **Peak grip force: 668 N** at 56.9 mm of travel, with the grip at 1.16 m (waist to chest height). With a stiffer soil (10 mm per decade) the peak is 571 N; with a softer one (20 mm) it is 809 N.
- **One operator at 500 N stalls at 51.9 mm, at 0.53 MPa**, and no overfill helps (best 0.53 MPa). The peak comes before the stop, so the operator cannot "push through" it.
- **Two operators on the T-handle** (334 N each at the peak) reach the stop at 2.00 MPa.
- Compaction work is **494 J** for the base soil (353 J and 705 J for the range). One operator at 500 N could give 853 J over the arc, so energy is not the limit; the mismatch between the force ratio and the soil curve is. A perfect match would need 58 % of the operator's capacity.

**R2 is at risk** (met with two operators, within the fill window of section 5, for the base soil). With the accepted R5 (500 N or less per operator, EPR-DDR-002), **R5 is met on paper** with two operators at 334 N each and the peak at 1,157 mm; one operator alone cannot make a 2 MPa block. On 2026-10-02 Amish decided that the operating chart is based on the softer soil until partner soils are measured: 809 N in all, 405 N per operator, still within R5's 500 N.

## 5. Fill tolerance (R1, R2)

The crank stop sits at the design end angle (6°), so the stop limits the force the linkage can deliver (section 6) and every block that reaches the stop is 90.0 mm high. The price is a narrow fill window. If the fill mass is e above nominal, the soil reaches 2 MPa at a height of 90(1 + e) mm.

*Table 4. Pressure and block height against fill error, two operators (1,000 N).*

| Fill error | Pressure | Block height |
| --- | --- | --- |
| -2 % | 1.49 MPa | 90.0 mm |
| -1 % | 1.72 MPa | 90.0 mm |
| 0 % | 2.00 MPa | 90.0 mm |
| +2 % | 2.69 MPa | 90.0 mm |
| +4 % | 1.15 MPa (operators stall) | 97.0 mm |

The fill must be between **0 and +2.7 %** of nominal, that is, 0 to 206 g over 7.64 kg of moist mix. Filling by struck volume alone cannot hold this, since loose density varies with moisture and handling. The proposal is to weigh each fill to about +1.3 % ± 100 g on a 10 kg hanging scale with 50 g divisions (now in the soil test kit, BOM item 9). R1 (height 90 ± 3 mm) is met on paper within this window.

### 5b. Operating chart for the softer design soil

Until partner soils are measured, the operating chart is written for the softer soil (pressure rising tenfold over the last 20 mm of the stroke), which Amish decided on 2026-10-02 (EPR-DEC-001). The peak pull is 809 N in total, 405 N for each of two operators, inside R5's 500 N [`sizing.py` section 4b]. The softer soil narrows the fill window to 0 to +2.0 % (0 to +153 g) from 0 to +2.7 %, because the operators stall sooner on an overfill.

*Table 5b. Operating chart, softer design soil, two operators.*

| Fill over nominal | Pressure at the stop | Block height | Peak pull per operator | Result |
| --- | --- | --- | --- | --- |
| -2 % (-153 g) | 1.63 MPa | 90.0 mm | 329 N | Too light: under 2 MPa |
| -1 % (-76 g) | 1.80 MPa | 90.0 mm | 365 N | Too light: under 2 MPa |
| 0 % (nominal) | 2.00 MPa | 90.0 mm | 405 N | Good, at the edge |
| +1.0 % (+76 g) | 2.22 MPa | 90.0 mm | 449 N | Good: the weighing target for this soil |
| +2.0 % (+153 g) | 2.46 MPa | 90.0 mm | 498 N | Good, at the edge: the operators are at their 500 N limit |
| +2.7 % (+206 g) | 1.07 MPa | 97.9 mm | 501 N | Operators stall: too heavy |
| +4 % (+305 g) | 0.90 MPa | 100.5 mm | 502 N | Operators stall: too heavy |

The weighing target for the softer soil is therefore +1.0 % (+76 g over nominal) with a tolerance of 75 g either way, against +1.3 % for the base soil. Each soil measured at a partner site gets its own row set, recomputed with `sizing.py`.

**Scoop rule.** A calibrated scoop may replace weighing only for a soil whose scoop-to-mass scatter has been measured inside the fill window (decided on 2026-10-02). Half the window is 103 g for the base soil (0.45 % of the moist fill, 34 g, is the largest standard deviation allowed, so that three standard deviations fit in the half window). The test: weigh 20 scoops of the prepared mix; accept the scoop only if the standard deviation is 34 g or less and the mean is on the weighing target. A new soil, a new moisture or a new scoop needs the test again.

## 6. Design load and structure (R8, R12)

**Design load.** The largest force the linkage can deliver is the operators' pull times the force ratio at the stop: 1,000 N x 173 = **173 kN** (4.26 MPa on the block). All members are checked at this abuse load and at the nominal 81.2 kN. It exceeds the R12 latch requirement of 1.5 x 81.2 = 121.8 kN.

*Table 5. Structural checks (safety factor on yield or capacity).*

| Member | Nominal 81.2 kN | Abuse 173 kN |
| --- | --- | --- |
| Toggle pins, 35 mm C45, double shear | 42 MPa (5.03) | 90 MPa (2.36) |
| Bush bearing, 2 x 28 mm links | 42 MPa (2.40) | 89 MPa (1.13) |
| Link net section at the 41 mm bush hole, 28 x 70 mm | 50 MPa (4.97) | 107 MPa (2.33) |
| Link buckling out of plane | SF 103 | SF 48 |
| Push rod net section at the slot, 60 mm square | 59 MPa (4.25) | 125 MPa (1.99) |
| Lid, 20 mm plate with two 20 x 70 mm ribs, 420 mm between hinge and latch pins | 73 MPa (3.43) | 155 MPa (1.61) |
| Lid deflection at mid-span | 0.08 mm | 0.17 mm |
| Hinge and latch pins, 30 mm, double shear | 29 MPa (7.43) | 61 MPa (3.49) |
| Mold long wall with the 16 x 50 mm belt | 89 MPa (2.80) | 190 MPa (1.31) |
| Columns, UPN 80 in tension | 37 MPa (6.77) | 79 MPa (3.18) |
| Columns at the 40 mm pin access hole | 47 MPa (5.30) | 101 MPa (2.49) |
| Mold to column bolts, 8 x M16 8.8 | SF 5.9 | SF 2.8 |
| Base beam, two 20 x 100 mm plates | 73 MPa (3.41) | 156 MPa (1.60) |
| Connecting link, 50 x 24 mm, 42.2 kN at the abuse case | | buckling SF 15.3 |
| Lever, 2 in schedule 40 at the socket mouth | 102 MPa at the 668 N peak (2.35) | 153 MPa at 1,000 N (1.57) |

The lowest factor is 1.13 (bush bearing at the abuse load). The connecting link acts 39.1 mm from the lever pivot at the stop and carries 42.2 kN at the abuse case; the two tie tubes from the lever bracket to the base beam carry a horizontal 34.1 kN. The mold wall bulges 0.08 mm at 2 MPa and the columns stretch 0.16 mm, so neither affects block size.

**The TRL 2 lid does not work.** A plain 22 mm plate, 220 mm wide, spanning the 420 mm between hinge and latch pins reaches 315 MPa at the nominal 81 kN, above yield. The ribbed lid in the model is the fix; it weighs 27 kg with its pins, which the operator lifts at the latch end every cycle (about 133 N).

**Fatigue (R8).** The highest nominal stress range per block is 89 MPa (mold wall), below the 243 MPa allowed for a FAT 71 welded detail at 50,000 cycles. Wear of bushes and mold faces cannot be estimated without soil data, so **R8 is not verifiable at TRL 3**.

**Safety features (R12).** If the lever is released at the end of the stroke, the soil rebound and column stretch return about **47 J** to it (roughly a 5 kg mass dropped 1 m), so it kicks back upward. The end pawl and the rest catch, spring pawls on the lever bracket, hold the crank pin at the end and at the start of the stroke; the end pawl takes the kickback end on. The T-handle stays 846 mm above the ground at the stop, and the grip is more than 1.5 m from the frame. The crank, connecting link and knee form a scissor point, covered by the linkage guard (BOM item 13). **R12 is met on paper.**

## 7. Ejection (R2, R5)

After pressing, the lever is returned to its rest stop, which lets the toggle fold under the weight of the piston while the block stays in the mold. The lid is opened and the lever is moved to the eject socket, a seesaw pivoted at x = 160 mm, z = 607.5 mm on the +X side. Its central arm, with a round nose 160 mm from the pivot, lifts the push rod by its foot, while the 200 mm slot in the rod lets it rise past the toggle pin.

Breaking the block free takes 4.64 kN of wall friction, 4.84 kN with the piston and block weight. The eject lever ratio is 10.3:1 or better (the nose is 139 to 160 mm from the pivot, measured across), so the **grip force is 470 N** or less, within R5 for one operator, over a 60° arc for the 160 mm lift (60 mm up to the block, 90 mm out, 10 mm clear). The 20 x 40 mm arm reaches 145 MPa in bending at the hub (SF 1.72).

## 8. Mass (R7)

*Table 6. Piece masses from the model at 7,850 kg/m³.*

| Piece | Mass |
| --- | --- |
| Base frame with lever bracket, ties and eject posts | 45.0 kg |
| Press core, columns and base beam | 28.2 kg |
| Mold box with hinge and latch lugs | 30.4 kg |
| Lid with ribs, hinge and latch pins | 27.0 kg |
| Piston and slotted push rod | 12.6 kg |
| Toggle links, pins and spacers | 24.6 kg |
| Lever hub, crank, shaft and crank pin | 8.2 kg |
| Lever pipe and T-handle (pipe alone 9.2 kg) | 10.4 kg |
| Eject seesaw, pivot pin, end pawl and rest catch | 7.0 kg |
| Linkage guard (expanded metal at 35 % of solid sheet) | 5.5 kg |
| Bolts | 1.2 kg |
| **Total** | **200.0 kg** |

**R7 was not met on paper** against the earlier 190 kg: the total is 200.0 kg against the 190 kg accepted by Amish on 2026-09-25 (EPR-DDR-002), 10 kg over. Of the 13 kg added since v0.2, 6.7 kg is the guard and bolts, which v0.2 did not count, and the rest is the round link ends, lugs, larger base plate and other parts added to make the press buildable (EPR-DDR-003). The heaviest piece is 45.0 kg, so the 50 kg piece limit is met. The press is 1,280 x 580 mm in plan, so it fits a 1.5 m pickup bed with the lever removed. On 2026-10-02 Amish set the R7 total at 200 kg, including the guard and bolts, and kept the 50 kg piece limit (EPR-DDR-003, A1), so R7 is now met on paper: 200.0 kg of steel plus about 5 g of felt dust seals is 199.996 kg, a margin of 4 g, which is no real margin; the weighed prototype at TRL 4 decides it (`sizing.py`, section 7).

## 9. Output and crew (R4)

*Table 7. Cycle time (assumed).*

| Step | Time |
| --- | --- |
| Weigh and fill | 25 s |
| Strike, close and latch | 8 s |
| Press, two on the lever | 10 s |
| Return lever, unlatch, open lid | 7 s |
| Move lever to the eject socket | 6 s |
| Eject | 6 s |
| Lift off, gauge, carry to the stack | 15 s |
| Return lever, brush the mold | 8 s |
| **Total** | **85 s** |

In 7 working hours the press makes **296 blocks per day**, 1 % short of the 300 in R4, so **R4 is at risk**. Two people at the press share the lever and block handling; two others dig, sieve and mix 2,375 kg of soil a day, which takes 9.8 of their 16 person-hours.

## 10. Material flow, house and carbon (R10, R11)

Per 100 blocks the crew digs 778 kg of soil, sieves out 117 kg of oversize, adds 33 kg of cement and 69 kg of water, and mixes 787 kg including 23 kg of remixed spill and rejects. The press turns out 764 kg of moist blocks, which cure to 712 kg after losing 51 kg of water (Figure 3 in EPR-PRC-001).

A small house with a 22 m perimeter, 2.7 m walls and 15 % openings has 50.5 m² of wall. At 33.3 blocks per m² with 10 mm joints it needs **1,683 blocks**, about 5.7 press days (8.9 m² of wall a day), and 556 kg of cement (11.1 bags of 50 kg). Its 7.07 m³ of walling embodies about **0.35 t CO2 as CSEB against 4.55 t as fired brick**, 7.6 % of the brick figure (**R11 met on paper**; mortar and transport excluded). R10 (strength with 8 % cement or less) is set by design at 5 % but cannot be verified without block tests.

## 11. Cost (R13)

Value-engineering target: USD 500. Estimated cost of the constructable design: USD 523 (USD 23 over the target) on indicative prices. The priced BOM totals **$523**: the $520 of 2026-10-01 plus $3 for eight felt or rubber dust seal washers at the bush faces (BOM line 5, decided on 2026-10-02; about $0.35 each from 2 mm felt or rubber sheet). `budget_usd` in `project.yaml` (a hypothetical control target) is unchanged, so **R13 is over the target by USD 23**. The steel alone (200 kg at about $1.30/kg) is about $260. The parts added to make the press buildable (EPR-DDR-003) account for the rise from $488. `budget_usd` is unchanged; the savings worth trying are in the Value engineering section of EPR-DEC-001.

## 12. Results against requirements

*Table 8. Every requirement in EPR-REQ-001 against this note.*

| ID | Requirement | Value | Target | Status |
| --- | --- | --- | --- | --- |
| R1 | Block dimensions | Cavity 290 x 140 mm; height 90.0 mm at the stop; wall bulge 0.08 mm | ± 2 mm plan, 90 ± 3 mm height | Met on paper, within the fill window |
| R2 | Compaction pressure | 2.00 MPa with two operators and fill 0 to +2.7 %; 0.53 MPa with one at 500 N | 2.0 MPa or more | At risk |
| R3 | Block strength | Depends on soil, mix and curing | 4 MPa dry, 2 MPa wet; 2.1 MPa minimum | Not verifiable at TRL 3 |
| R4 | Output | 296 blocks per day, crew of four | 300 or more | At risk |
| R5 | Operator force and grip height | Peak 668 N total (334 N each for two) at 1.16 m; 809 N (405 N each) for the softer design soil of the operating chart; grip 0.86 to 1.89 m; eject 470 N | 500 N or less per operator; grip 0.8 to 1.9 m; peak at 1.0 m or higher | Met on paper (two operators) |
| R6 | Garage-buildable | Plate, sections, pipe and tube; turned pins, shafts and bushes bought | Stick welder, grinder, drill press | Met (design review) |
| R7 | Movable | 200 kg total (199.996 kg with the dust seals); heaviest piece 45.0 kg; plan 1.28 x 0.58 m | 200 kg total including guard and bolts (190 kg until 2026-10-02); 50 kg per piece; 1.5 m bed | Met on paper (piece limit met) |
| R8 | Durability | Stress range 89 MPa against 243 MPa; bushes, grease nipples | 50,000 blocks; replaceable bushes | Not verifiable at TRL 3 (wear) |
| R9 | Soil test kit | Field tests, chart and a 10 kg scale for fill weighing | Go or no-go in 1 h, full result in 24 h | Met (design review); accuracy not verifiable at TRL 3 |
| R10 | Low stabilizer use | 5 % cement, 0.33 kg per block | 8 % or less reaching R3 | Not verifiable at TRL 3 |
| R11 | Embodied carbon | 7.6 % of fired brick | 25 % or less | Met on paper |
| R12 | Safe operation | Rest catch and end pawl on the crank pin; latch and lid rated 173 kN; guard over the linkage; grip over 1.5 m from the frame | No free fall; latch 1.5 x (121.8 kN); guards or 100 mm | Met on paper |
| R13 | Affordable | $523 | At or below the $500 value-engineering target | **Over the value-engineering target by USD 23** |
| R14 | Open and documented | Model, drawing, BOM and this note | Build by an outside welder without the author | Not verifiable at TRL 3 |

> **Safety:** The press delivers 81 kN at 2 MPa and up to 173 kN if two people pull hard at the stop. Keep hands out of the mold, the linkage and the eject arm while anyone is on the lever. The lever kicks back with about 47 J if released at the end of the stroke; engage the end pawl before letting go. Never open the lid until the lever is back on its rest stop.

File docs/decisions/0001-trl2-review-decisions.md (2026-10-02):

---
doc_id: EPR-DDR-001
title: EarthPress TRL 2 review decisions
project: EarthPress
doc_type: Design decision record
version: "0.3"
status: Draft
date: '2026-10-02'
author: Amish Chadha
license: CERN-OHL-S-2.0
revisions:
- version: "0.1"
  date: '2026-09-25'
  author: Amish Chadha
  change: Record the TRL 2 review items adopted as recommended for TRL 3 under Amish's 2026-09-25 instruction, the items that remain open, and new items from EPR-CAL-001
- version: "0.2"
  date: '2026-09-25'
  author: Amish Chadha
  change: Recommendations accepted by Amish (DDR-002)
- version: "0.3"
  date: '2026-10-02'
  author: Amish Chadha
  change: "Item 8 decided by Amish on 2026-10-02 (EPR-DEC-001)"
---

# 0001: TRL 2 review decisions

- **Date:** 2026-09-25
- **Status:** accepted; item 8 decided on 2026-10-02. Items 1 to 7 and 9 to 16: Decided by Amish, 2026-09-25: go with recommendation (see EPR-DDR-002). Item 8 had no recommendation on 2026-09-25; a recommendation was written later and Amish approved it on 2026-10-02 ("i approve your recommendations for all 555 open decisions."; EPR-DEC-001).

## Context

The TRL 2 review note (`docs/REVIEW.md`, session of 2026-09-25, /populate) listed nine items as "Proposed, awaiting Amish", eight of them with a recommendation. On 2026-09-25 Amish asked for this batch of repos to be taken through the usual process with the instruction "you know the drill, nothing gets past TRL 3". He has not reviewed the EarthPress items one by one. Under that instruction, each item that has a recommendation is adopted as recommended so that the TRL 3 work can proceed, and stays open for his review. Items without a recommendation stay open. TRL 4 is on hold by Amish's instruction. Later on 2026-09-25 Amish wrote "i accept all your recommendations, go with them across all repos", so every item with a recommendation is now decided (EPR-DDR-002).

EarthPress uses none of the shared components in this batch (FieldNode, CellGuard, MotionCore, ThermaCart, TwinKit, CalRig) or SwapCell, so there are no cross-repo interfaces to keep consistent.

## Options considered

The options for items 1 to 9 are in `docs/REVIEW.md` (TRL 2 section). Items 10 to 16 are new at TRL 3 and come from EPR-CAL-001; their options are in Table 2.

## Decision

*Table 1. TRL 2 items, decided.*

| # | Item | Status | Where it now lives |
| --- | --- | --- | --- |
| 1 | Mechanism: bottom piston with a toggle and one lever (CINVA-Ram pattern); the bottle-jack variant documented later | Decided by Amish, 2026-09-25: go with recommendation | EPR-PRC-001 v0.3, `cad/src/model.py` |
| 2 | Lever layout: raise the pivot for a longer arc and a higher grip at the end of the stroke | Decided by Amish, 2026-09-25: go with recommendation. EPR-CAL-001 section 3 shows the specific figures (800 mm pivot, 100° arc) do not work with a 1.65 m grip radius, because the grip would pass below the ground; the intent is met with a low pivot and a 59° arc from a nearly upright start (grip 1.89 to 0.86 m). The geometry change is item 16a | EPR-CAL-001 section 3, `cad/src/model.py` |
| 3 | Block: flat 290 x 140 x 90 mm (Auroville module); interlocking inserts a later option | Decided by Amish, 2026-09-25: go with recommendation | EPR-REQ-001 v0.3, EPR-PRC-001 v0.3 |
| 4 | Compaction target: 2 MPa | Decided by Amish, 2026-09-25: go with recommendation | EPR-REQ-001 R2 |
| 5 | Stabilizer: 5 % cement by dry mass, lime for clay-rich soils, confirmed with partner soils | Decided by Amish, 2026-09-25: go with recommendation | EPR-PRC-001 v0.3, EPR-REQ-001 R10 |
| 6 | Meeting R7: 12 mm base plate and a bolted mold (rather than relaxing R7) | Decided by Amish, 2026-09-25: go with recommendation. The frame is now two bolted pieces (36.6 and 27.7 kg) and no piece exceeds 37 kg, but the total is 187 kg against 140 kg (item 13) | `cad/src/model.py`, EPR-CAL-001 section 8 |
| 7 | Soil test kit: field tests only at TRL 3 | Decided by Amish, 2026-09-25: go with recommendation | EPR-PRC-001 v0.3, BOM item 9 |
| 9 | Budget and wording: no change to `budget_usd` ($450); pitch and problem unchanged | Decided by Amish, 2026-09-25: go with recommendation. `budget_usd` was then raised to $500 under item 14, which supersedes the budget part of this item | `project.yaml` (unchanged) |

No pitch or problem rewording was recommended at TRL 2, so `project.yaml` and `README.md` keep the TRL 2 wording.
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

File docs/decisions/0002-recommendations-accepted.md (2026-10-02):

---
doc_id: EPR-DDR-002
title: EarthPress recommendations accepted
project: EarthPress
doc_type: Design decision record
version: "0.2"
status: Draft
date: '2026-10-02'
author: Amish Chadha
license: CERN-OHL-S-2.0
revisions:
- version: "0.1"
  date: '2026-09-25'
  author: Amish Chadha
  change: Record Amish's acceptance of every recommendation in EPR-DDR-001 and docs/REVIEW.md, what changed in the repo, and the items still open
- version: "0.2"
  date: '2026-10-02'
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

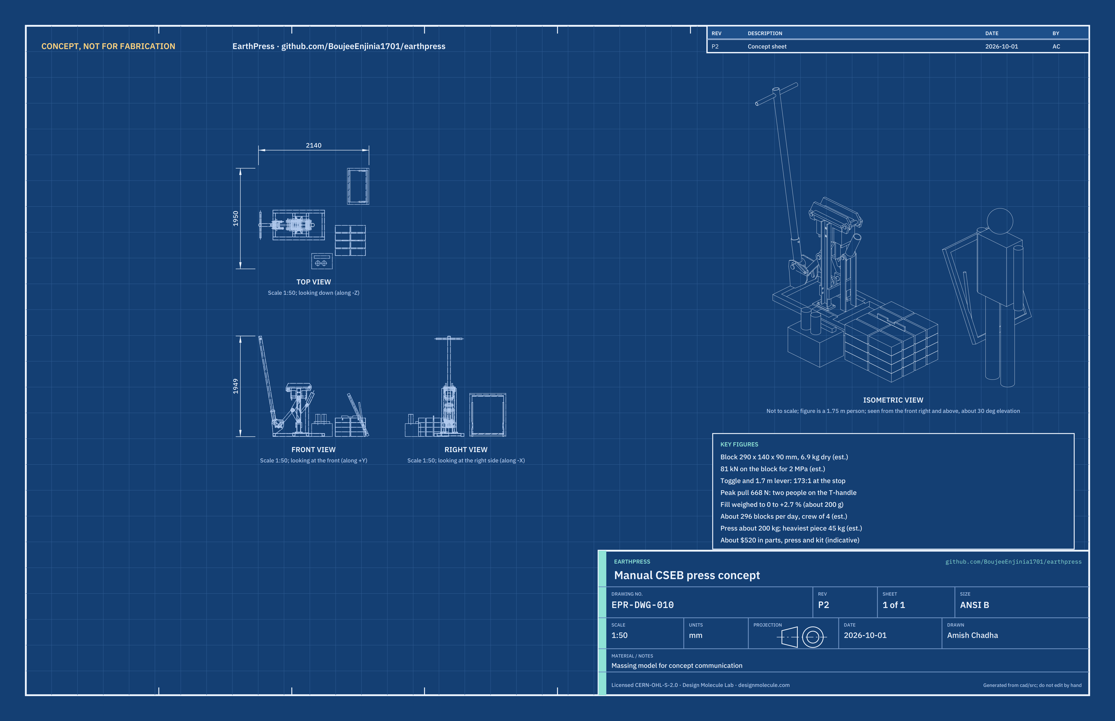
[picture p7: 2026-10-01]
media/concept-blueprint.png

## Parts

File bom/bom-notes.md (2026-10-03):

# BOM notes

- Rows 1 to 10 match the numbered callouts in `media/exploded.png`. Rows 11 to 13 (hardware and finish, consumables, linkage guard) have no callout.
- Every line is priced. Unit costs are indicative USD prices for a TRL 3 design, based on mild steel at about $1.30/kg plus cutting, and bought turned pins, shafts and bushes. Steel masses come from the model (`cad/src/model.py`, EPR-CAL-001 section 8). They are to be replaced with local quotes before any build.
- Total of rows 1 to 13: **$523** (was $520 before the dust seals of 2026-10-02), which is $23 over the $500 `budget_usd` in `project.yaml` (R13 not met on paper). Amish raised the budget from $450 to $500 on 2026-09-25 (EPR-DDR-001 item 14, EPR-DDR-002). `budget_usd` is unchanged; savings worth trying are in the register (`docs/06-design-decisions.md`).
- Changes for the constructable design (2026-10-01, EPR-DDR-003, $488 to $520): tapped mold flanges and hinge and latch lugs, lid pins in rib ears, round-ended links with spacers, piston end skirts, larger base plate, bolted tie tabs, rest catch and end pawl, cranked eject arm, lever locking pin, modelled linkage guard, more fixings.
- Changes from TRL 2 ($403): heavier frame with a base beam (two bolted pieces), ribbed lid, larger toggle pins and links with case-hardened bushes, 2 in lever pipe with a T-handle, eject seesaw and end pawl, 10 kg scale in the test kit, and the linkage guard.
- Not included: welding labor, cement, water, soil, curing covers and transport.
- The loose soil and the stack of blocks in the renders are context only and are not BOM lines.
- Decided on 2026-10-02 (EPR-DEC-001): the case-hardened steel bushes get simple felt or rubber dust seals at their faces (now in line 5: eight washers, 2 mm felt or rubber, 50 mm outside and 35.5 mm bore, about $0.35 each, $3 added to line 5 on 2026-10-02, EPR-CAL-001 v0.6); the mold walls stay plain 12 mm plate with no liners for the prototype.

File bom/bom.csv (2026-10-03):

item | qty | spec | supplier | unit_cost_usd | make_buy | notes
1 Frame: base on skids and press core | 1 | Base (one welded piece, about 45 kg): two 60 x 60 x 3 mm tube skids 1.0 m; four 50 x 50 x 3 mm cross tubes welded between the skids with their tops flush; 12 mm base plate 315 x 340 mm; two shaped 10 mm lever bracket plates with a 30 mm rest stop bar under the crank; two 40 mm round tie tubes, 3 mm wall, with 10 mm bolted end tabs; two 10 mm eject posts. Core (one welded piece, about 28 kg): two UPN 80 columns about 0.84 m, webs toward the mold, with 40 mm access holes for the base and upper pins; two 20 x 100 mm base beam plates welded to the column flanges; two 20 mm base pin lugs; two 16 mm column feet. About 73 kg of mild steel in two bolted pieces (EPR-DDR-003) | Local steel stockist and welder | 107.00 | make | Indicative: 73 kg at about $1.30/kg plus about $12 of cutting and drilling; welding labor not included
2 Mold box | 1 | 12 mm plate walls round a 290 x 140 x 200 mm cavity; 16 x 50 mm stiffening belt round the top; two 16 mm side flanges, each drilled and tapped M16 in four places; two 20 mm hinge lugs and two 20 mm latch lugs on the belt ends. No guide strap (the piston is guided by its end skirts). About 30 kg | Local steel stockist and welder | 58.00 | make | Indicative: 30 kg at about $1.30/kg plus about $15 for grinding the cavity faces flat and square and about $4 for tapping
3 Lid with ribs, hinge and latch | 1 | 20 mm plate 360 x 230 mm with two 20 mm ribs, 70 mm high over the plate, cut long at both ends as ears for the 30 mm hinge pin and the 30 mm latch pin; latch pin with a T-handle; rated for 173 kN block force (EPR-CAL-001). About 27 kg | Local steel stockist and welder; turned pins from a machine shop | 44.00 | make | Indicative: 25 kg of steel about $32 plus two turned C45 pins about $6 each
4 Piston and slotted push rod | 1 | 25 mm plate 288 x 138 mm with two 12 mm end skirts 60 mm deep, on a 60 x 60 mm solid bar with a 37 x 200 mm lost-motion slot. About 13 kg | Local steel stockist and welder | 25.00 | make | Indicative: 13 kg of steel about $17 plus about $8 to drill and grind the slot
5 Toggle links, pins and bushes | 1 | Four 28 x 70 mm links with round ends, 245 mm between centers; one 24 x 50 mm connecting link with round ends, 420 mm between centers; three 35 mm C45 turned pins with circlips (base and knee 192 mm, upper 128 mm); ten case-hardened steel bushes 35 mm bore, 41 mm outside; four spacer tubes (two 16 mm and two 20 mm long); six grease nipples; eight felt or rubber dust seal washers, 2 mm thick, 50 mm outside and 35.5 mm bore, one on each outer link face round a bush | Bearing and power transmission shop; local welder | 94.00 | buy | Indicative: link steel about $26; pins 3 x $10; bushes 10 x $3; spacers about $2; grease nipples about $3; dust seal washers 8 x about $0.35 | cut from 2 mm wool felt or rubber sheet | rounded to $3 (added 2026-10-02)
6 Lever, crank hub and T-handle | 1 | 1.7 m of 2 in schedule 40 steel pipe (60.3 x 3.91 mm) with rubber grips and a 0.5 m T-handle for a second operator; 80 mm hub with two 20 x 50 mm round-ended crank plates (107 mm crank) and a 250 mm socket, on a 40 mm turned shaft in the bracket; 30 mm crank pin 112 mm long; 12 mm locking pin with R-clip through socket and lever | Local steel stockist and welder; turned shaft and pins from a machine shop | 44.00 | make | Indicative: pipe about $18; hub; crank and socket steel about $12; shaft about $8; grips about $4; locking pin about $2
7 Eject lever, rest catch and end pawl | 1 | Eject seesaw: 60 mm hub on a 30 mm pin between the two eject posts, cranked 20 mm arm with a round nose that pushes on the foot of the push rod (160 mm from the pivot), 250 mm socket for the main lever at 30 degrees. End pawl (+Y side) and rest catch (-Y side): each a 12 mm plate on a 16 mm pivot shaft through a bracket plate, with a release handle outside and a return spring; they catch the crank pin at the end and at the start of the stroke. Rubber sleeve for the rest stop bar | Local steel stockist and welder | 22.00 | make | Indicative: 7 kg of steel about $9; pin about $6; two springs about $4; rubber sleeve about $3
8 Soil sieve | 1 | 5 mm welded wire mesh in a 700 x 900 mm timber frame with a hinged prop | Local hardware shop | 18.00 | make | Indicative
9 Soil test kit | 1 | Two 1 L clear jars with lids; 600 x 40 x 40 mm shrinkage box; three measuring buckets; 10 kg hanging scale with 50 g divisions for weighing each fill; salt for dispersion; laminated test chart | Local hardware shop and market | 25.00 | buy | Indicative; field tests only (EPR-DDR-001 item 7); scale changed from 25 kg to 10 kg for the fill tolerance in EPR-CAL-001
10 Block gauge | 1 | 12 mm steel flat bar 340 x 40 mm with two 40 mm legs 292 mm apart inside (longest good block) and a 93 mm notch in the top edge (tallest good block) | Local welder | 8.00 | make | Indicative
11 Hardware and finish | 1 | Eight M16 x 20 8.8 hex bolts with washers (mold flanges, into tapped holes); eight M12 x 40 8.8 bolts with nuts and washers (column feet); four M12 x 50 8.8 bolts with nuts and washers (tie tabs); four M10 x 30 bolts and four M10 x 50 bolts with 35 mm spacer tubes (guard); circlips; primer and paint | Local hardware shop | 40.00 | buy | Indicative; no exploded-view callout
12 Fabrication consumables | 1 | Welding rods, cutting and grinding discs, M16 tap | Local hardware shop | 20.00 | buy | Indicative; no exploded-view callout
13 Linkage guard | 1 | Expanded metal (about 2 mm strand) on a 20 x 20 x 3 mm angle frame: top and both sides over the crank, connecting link and knee (R12 pinch points); two feet bolted to the base plate and two spacer brackets bolted to each lever bracket plate. About 5.5 kg | Local steel stockist | 18.00 | make | Indicative; no exploded-view callout

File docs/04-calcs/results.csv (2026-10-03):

section | quantity | value | unit
block | Block face area | 0.0406 | m2
block | Block volume | 3.65 | L
block | Dry block mass | 6.94 | kg
block | Moist mass at the press | 7.64 | kg
block | Cement per block | 0.33 | kg
block | Force for 2 MPa (nominal) | 81.2 | kN
block | Force for 4 MPa | 162.4 | kN
block | Loose to pressed height ratio | 1.67
block | Loose dry density in the mold | 1140 | kg/m3
kin | Toggle link length | 245 | mm
kin | Toggle angle at start / end (from vertical) | 29.3 / 6.0 | deg
kin | Piston stroke | 60.0 | mm
kin | Base pin height / upper pin height at end | 298 / 785 | mm
kin | Lever angle at start / end (from +X) | 99.6 / 158.8 | deg
kin | Lever arc | 59.2 | deg
kin | Grip path length | 1.71 | m
kin | Grip height at start / end | 1893 / 863 | mm
kin | Largest arc inside 0.9 to 1.6 m with this grip radius | 24.5 | deg
kin | Highest grip height over the arc (the lever passes upright) | 1893 | mm
kin | Grip inside the R5 band 0.8 to 1.9 m (EPR-DDR-002) | yes
kin | Arc of the TRL 2 proposal (800 mm pivot, 100 deg) | 100 | deg
kin | Lowest grip height for that proposal (symmetric arc) | -464 | mm
kin | Overall force ratio at the end of the stroke | 173 | :1
kin | Force ratio at mid-stroke (30 mm) | 20.0 | :1
kin | Force ratio rises monotonically to the stop | yes
grip | Peak grip force, base soil (14 mm per decade) | 668 | N
grip | Travel at the peak | 56.9 | mm
grip | Grip height at the peak | 1157 | mm
grip | Peak at 1.0 m or higher (R5, EPR-DDR-002) | yes
grip | Grip force at the end of the stroke | 469 | N
grip | Peak grip force, soil 10 mm per decade | 571 | N
grip | Peak grip force, soil 20 mm per decade | 809 | N
grip | One operator at 500 N: stalls at travel | 51.9 | mm
grip | One operator at 500 N: pressure reached | 0.53 | MPa
grip | Two operators at 1,000 N: reach the stop | yes
grip | Two operators: pressure at the stop | 2.00 | MPa
grip | Share per operator at the peak (two on the T-handle) | 334 | N
grip | Compaction work, base soil | 494 | J
grip | Compaction work, soil 10 mm per decade | 353 | J
grip | Compaction work, soil 20 mm per decade | 705 | J
grip | Work one operator can give at 500 N over the arc | 853 | J
grip | Matching efficiency needed for one operator | 58 | %
profile | s = 0.0 mm | 0.00 kN; ratio 14.8; grip 0 N; height 1893 mm
profile | s = 20.0 mm | 0.11 kN; ratio 17.4; grip 6 N; height 1811 mm
profile | s = 30.1 mm | 0.59 kN; ratio 20.0; grip 29 N; height 1735 mm
profile | s = 40.0 mm | 3.04 kN; ratio 25.0; grip 122 N; height 1621 mm
profile | s = 45.0 mm | 6.90 kN; ratio 29.5; grip 234 N; height 1540 mm
profile | s = 50.0 mm | 15.67 kN; ratio 37.5; grip 417 N; height 1429 mm
profile | s = 53.0 mm | 25.77 kN; ratio 46.5; grip 554 N; height 1337 mm
profile | s = 55.0 mm | 35.73 kN; ratio 56.5; grip 632 N; height 1257 mm
profile | s = 57.0 mm | 49.76 kN; ratio 74.5; grip 668 N; height 1150 mm
profile | s = 59.0 mm | 68.67 kN; ratio 115.8; grip 593 N; height 994 mm
profile | s = 60.0 mm | 81.20 kN; ratio 173.0; grip 469 N; height 863 mm
fill | Fill mass window for 2 MPa at the stop, two operators | +0.0 to +2.7 | %
fill | Same window in grams of moist mix | +0 to +206 | g
fill | Fill -2 %: pressure, block height | 1.49 MPa, 90.0 mm
fill | Fill -1 %: pressure, block height | 1.72 MPa, 90.0 mm
fill | Fill +0 %: pressure, block height | 2.00 MPa, 90.0 mm
fill | Fill +2 %: pressure, block height | 2.69 MPa, 90.0 mm
fill | Fill +4 %: pressure, block height | 1.15 MPa, 97.0 mm
fill | Best pressure one operator reaches at any overfill | 0.53 | MPa
chart | Design soil: pressure rises tenfold over the last | 20.0 | mm
chart | Peak grip force at nominal fill, total | 809 | N
chart | Peak grip force at nominal fill, per operator (two on the T-handle) | 405 | N
chart | Fill -2.0 % (-153 g): pressure, height, peak grip per operator | 1.63 MPa, 90.0 mm, 329 N, at the stop
chart | Fill -1.0 % (-76 g): pressure, height, peak grip per operator | 1.80 MPa, 90.0 mm, 365 N, at the stop
chart | Fill +0.0 % (+0 g): pressure, height, peak grip per operator | 2.00 MPa, 90.0 mm, 405 N, at the stop
chart | Fill +1.0 % (+76 g): pressure, height, peak grip per operator | 2.22 MPa, 90.0 mm, 449 N, at the stop
chart | Fill +1.3 % (+99 g): pressure, height, peak grip per operator | 2.29 MPa, 90.0 mm, 463 N, at the stop
chart | Fill +2.0 % (+153 g): pressure, height, peak grip per operator | 2.46 MPa, 90.0 mm, 498 N, at the stop
chart | Fill +2.7 % (+206 g): pressure, height, peak grip per operator | 1.07 MPa, 97.9 mm, 501 N, operators stall
chart | Fill +4.0 % (+305 g): pressure, height, peak grip per operator | 0.90 MPa, 100.5 mm, 502 N, operators stall
chart | Fill window for 2 MPa at the stop, softer soil, two operators | +0.0 to +2.0 | %
chart | Weighed fill target, base soil window, centre | +103 | g over nominal
chart | Half-width of the fill window | 103 | g
chart | Scoop rule: largest scoop-to-mass standard deviation allowed (three of them fill half the window) | 34 | g
chart | Scoop rule: as a share of the moist fill mass | 0.45 | %
lime | Lime fraction of dry soil (assumed starting value) | 8 | %
lime | Dry soil per block with lime | 6.43 | kg
lime | Hydrated lime per block | 0.51 | kg
lime | Hydrated lime per 100 blocks (cement: 33 kg) | 51 | kg
lime | Water per block (10 % of dry mix mass, as for cement) | 0.69 | kg
lime | Moist fill mass per block (unchanged: same dry block mass and water) | 7.64 | kg
lime | Damp curing, cement default | 4.0 | weeks
lime | Damp curing, lime option (assumed, longer) | 8.0 | weeks
str | Abuse load: 1,000 N at the grip at the stop | 173.0 | kN
str | Equivalent pressure on the block | 4.26 | MPa
str | R12 latch requirement, 1.5 x nominal block force | 121.8 | kN
str | Toggle pin 35 mm, double shear, nominal | 42 MPa (SF 5.03)
str | Bush bearing, 2 x 28 mm links, nominal | 42 MPa (SF 2.40)
str | Link net section at the pin hole, nominal | 50 MPa (SF 4.97)
str | Link buckling out of plane, nominal | 41 kN on 4211 kN (SF 103.2)
str | Push rod net section at the slot, nominal | 59 MPa (SF 4.25)
str | Lid bending (plate 20 + ribs 20 x 70), nominal | 73 MPa (SF 3.43)
str | Lid deflection at mid-span, nominal | 0.08 | mm
str | Hinge and latch pins 30 mm, double shear, nominal | 29 MPa (SF 7.43)
str | Mold long wall with belt, nominal | 89 MPa (SF 2.80)
str | Mold wall bulge at 2 MPa | 0.078 | mm
str | Columns UPN 80 in tension, nominal | 37 MPa (SF 6.77)
str | Column net section at the 40 mm access hole, nominal | 47 MPa (SF 5.30)
str | Mold to column bolts, 8 x M16 8.8, nominal | 81 kN on 482 kN (SF 5.9)
str | Base beam, 2 x 20 x 100 plates, nominal | 73 MPa (SF 3.41)
str | Toggle pin 35 mm, double shear, abuse | 90 MPa (SF 2.36)
str | Bush bearing, 2 x 28 mm links, abuse | 89 MPa (SF 1.13)
str | Link net section at the pin hole, abuse | 107 MPa (SF 2.33)
str | Link buckling out of plane, abuse | 87 kN on 4211 kN (SF 48.4)
str | Push rod net section at the slot, abuse | 125 MPa (SF 1.99)
str | Lid bending (plate 20 + ribs 20 x 70), abuse | 155 MPa (SF 1.61)
str | Lid deflection at mid-span, abuse | 0.17 | mm
str | Hinge and latch pins 30 mm, double shear, abuse | 61 MPa (SF 3.49)
str | Mold long wall with belt, abuse | 190 MPa (SF 1.31)
str | Columns UPN 80 in tension, abuse | 79 MPa (SF 3.18)
str | Column net section at the 40 mm access hole, abuse | 101 MPa (SF 2.49)
str | Mold to column bolts, 8 x M16 8.8, abuse | 173 kN on 482 kN (SF 2.8)
str | Base beam, 2 x 20 x 100 plates, abuse | 156 MPa (SF 1.60)
str | TRL 2 lid, plain 22 mm plate, at nominal load | 315 | MPa
str | Connecting link moment arm about the lever pivot at the stop | 39.1 | mm
str | Connecting link force at the abuse case | 42.2 | kN
str | Connecting link buckling capacity (50 x 24 flat) | 645 kN (SF 15.3)
str | Tie tube load (two 40 mm tubes), horizontal component | 34.1 | kN
str | Lever 2 in sch 40 at the socket mouth, working peak | 102 MPa (SF 2.35)
str | Lever 2 in sch 40 at the socket mouth, abuse | 153 MPa (SF 1.57)
str | Lowest safety factor on yield or capacity (abuse case) | 1.13
str | Highest nominal stress range per block | 89 | MPa
str | Allowed range, FAT 71 welded detail at 50,000 cycles | 243 | MPa
str | Column stretch at 2 MPa | 0.16 | mm
str | Energy returned to the lever if released at the end | 47 | J
str | Clearance from the T-handle to the ground at the end | 846 | mm
ej | Wall friction to break the block free | 4.64 | kN
ej | Ejection force including piston and block weight | 4.84 | kN
ej | Eject lever ratio | 10.3 | :1
ej | Grip force to eject | 470 | N
ej | Eject arm, 20 x 40 mm, bending at the hub (SF on yield) | 145 MPa (SF 1.72)
ej | Force to lift the lid at the latch end | 133 | N
ej | Eject lift (60 mm to the block, 90 mm out, 10 mm clear) | 160 | mm
ej | Eject lever arc | 60.0 | deg
mass | Base frame with lever bracket, ties and eject posts | 45.0 | kg
mass | Press core, columns and base beam | 28.2 | kg
mass | Mold box with hinge and latch lugs | 30.4 | kg
mass | Lid with ribs, hinge and latch pins | 27.0 | kg
mass | Piston and slotted push rod | 12.6 | kg
mass | Toggle links, pins and spacers | 24.6 | kg
mass | Lever hub, crank, shaft and crank pin | 8.2 | kg
mass | Lever pipe and T-handle | 10.4 | kg
mass | Eject seesaw, pivot pin, end pawl and rest catch | 7.0 | kg
mass | Linkage guard | 5.5 | kg
mass | Bolts | 1.2 | kg
mass | Press total, steel | 200.0 | kg
mass | Heaviest single piece | 45.0 | kg
mass | Margin to the R7 total of 200 kg including guard and bolts (2026-10-02); negative is over | 0.01 | kg
mass | Eight felt dust seal washers (assumed 0.30 g/cm3; not steel) | 0.0047 | kg
mass | Press total with the dust seals | 199.996 | kg
mass | R7 total met (200 kg or less with the seals, heaviest piece 50 kg or less) | yes
mass | Lever pipe alone (removable) | 9.2 | kg
out | Cycle time | 85 | s
out | Blocks per 8 h day (7 h working) | 296
out | Soil dug per day | 2375 | kg
out | Sieving and mixing, person-hours | 9.8 | h
out | Available from two helpers | 16 | h
flow | Dug soil per 100 blocks | 778 | kg
flow | Oversize removed | 117 | kg
flow | Sieved soil | 661 | kg
flow | Cement added | 33 | kg
flow | Water added | 69 | kg
flow | Moist mix incl. remixed rejects | 787 | kg
flow | Spill and rejects, remixed | 23 | kg
flow | Pressed blocks | 764 | kg
flow | Cured blocks | 712 | kg
flow | Water lost in curing | 51 | kg
house | Wall area, small house | 50.5 | m2
house | Blocks per m2 (10 mm joints) | 33.3
house | Blocks for the house | 1683
house | Press days | 5.7
house | Wall per day | 8.9 | m2
house | Cement for the house | 556 | kg
house | 50 kg bags | 11.1
house | Walling volume | 7.07 | m3
house | CO2, CSEB | 0.35 | t
house | CO2, fired brick | 4.55 | t
house | CSEB as a share of fired brick | 7.6 | %
cost | BOM total, press and kit | 523 | USD
cost | Budget in project.yaml | 500 | USD
cost | Under budget by | -23 | USD
cost | Steel in the press at the indicative price | 260 | USD

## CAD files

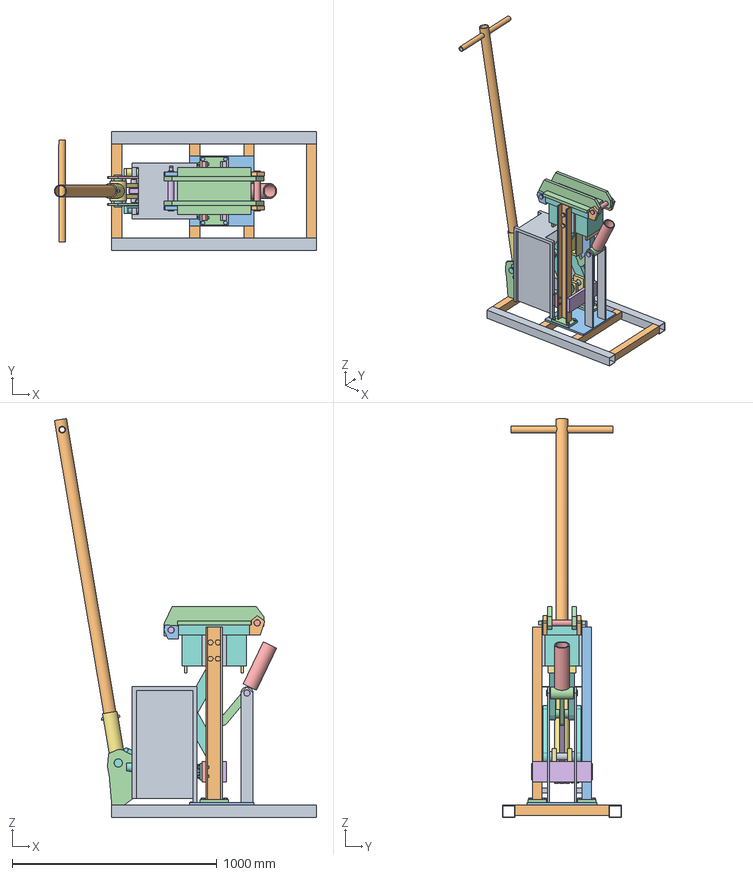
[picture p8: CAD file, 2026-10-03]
cad/step/earthpress-assembly.step
1279.8 x 580.0 x 1947.4 mm

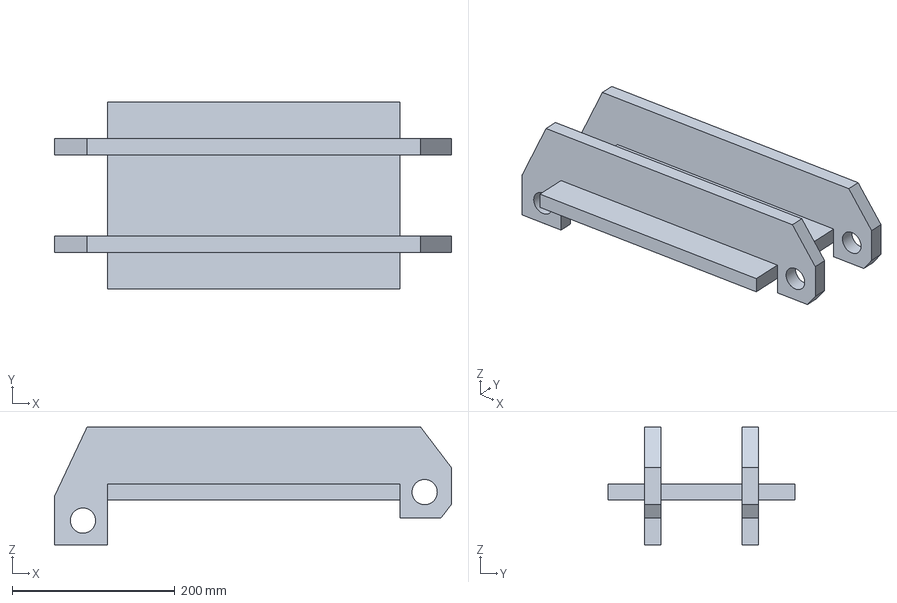
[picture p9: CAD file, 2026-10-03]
cad/step/earthpress-lid.step
488.0 x 230.0 x 145.0 mm

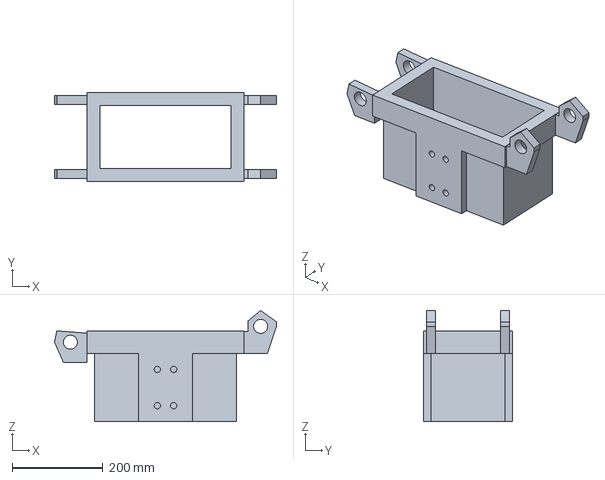
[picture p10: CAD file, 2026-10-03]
cad/step/earthpress-mold.step
490.0 x 196.0 x 245.0 mm

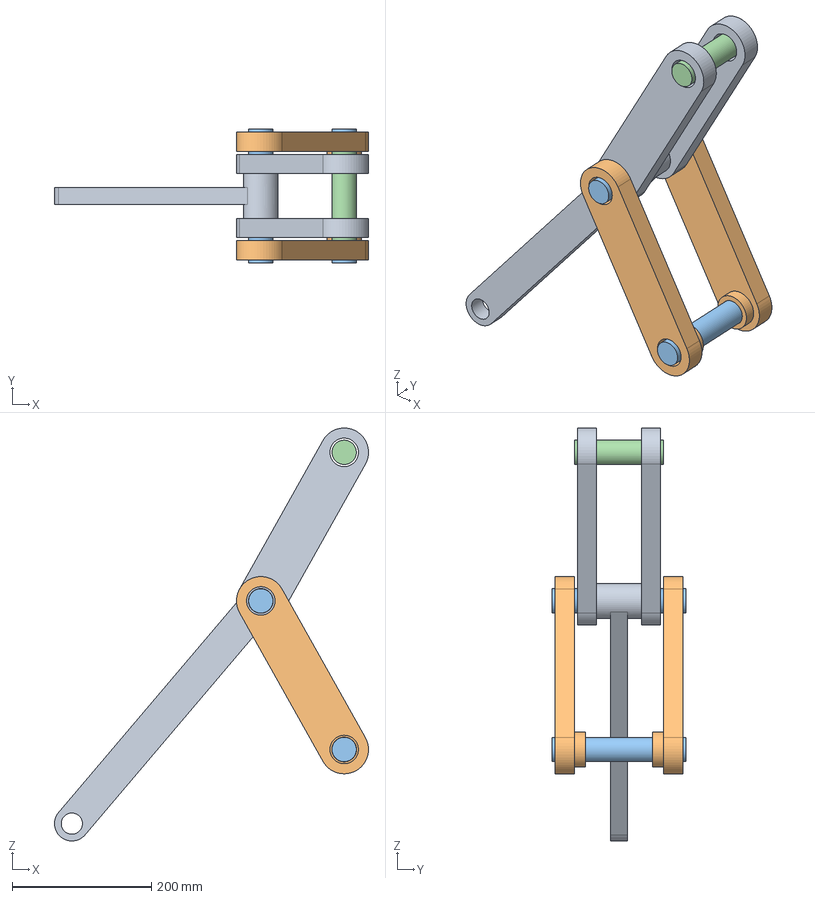
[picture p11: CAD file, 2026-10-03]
cad/step/earthpress-toggle.step
451.6 x 192.0 x 593.9 mm

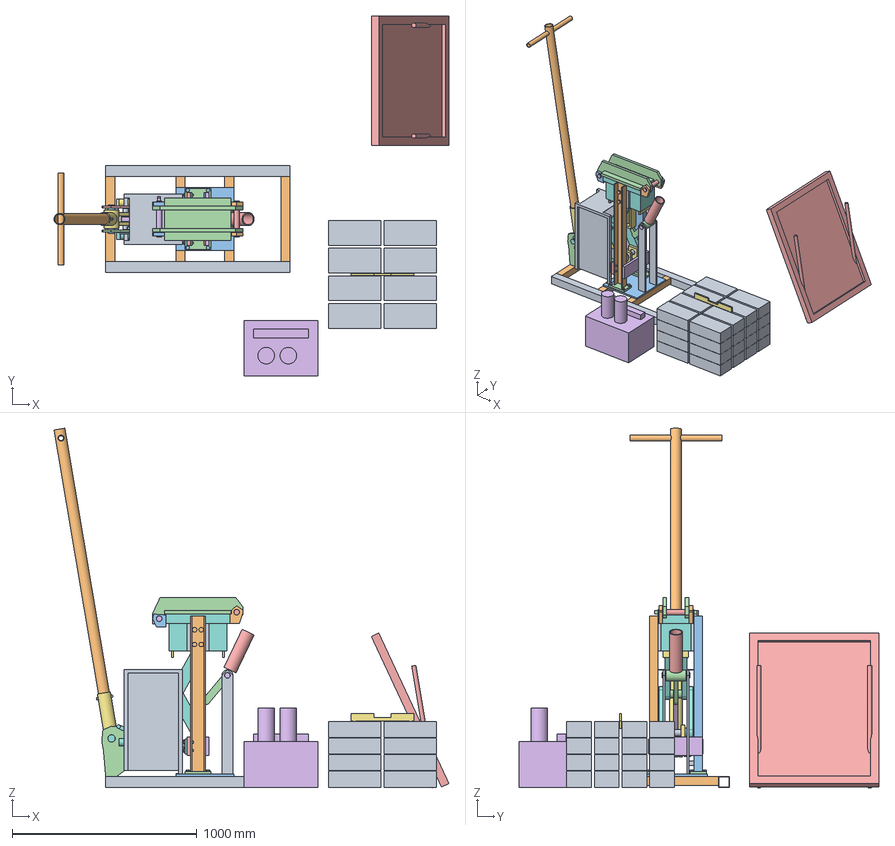
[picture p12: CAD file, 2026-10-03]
cad/step/earthpress-set.step
2140.4 x 1950.0 x 1949.4 mm

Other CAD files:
cad/stl/earthpress-assembly.stl
cad/stl/earthpress-lid.stl
cad/stl/earthpress-mold.stl
cad/stl/earthpress-set.stl
cad/stl/earthpress-toggle.stl

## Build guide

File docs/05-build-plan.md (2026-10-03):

---
doc_id: EPR-BLD-001
title: EarthPress prototype build plan
project: EarthPress
doc_type: Build plan
version: "0.4"
status: Draft
date: '2026-10-02'
author: Amish Chadha
license: CERN-OHL-S-2.0
revisions:
  - version: "0.1"
    date: '2026-10-01'
    author: Amish Chadha
    change: First build plan; design made constructable (EPR-DDR-003)
  - version: "0.2"
    date: '2026-10-01'
    author: Amish Chadha
    change: Budget treated as a value-engineering target
  - version: "0.3"
    date: '2026-10-02'
    author: Amish Chadha
    change: "Section 2: the changes recorded in EPR-DDR-003 accepted by Amish on 2026-10-02"
  - version: "0.4"
    date: '2026-10-02'
    author: Amish Chadha
    change: 'Dust seals at the bush faces added (parts, steps 5 to 7, pictures); section 3.15 soil test kit procedure with the operating chart, scoop rule and lime mix chart; cost USD 523'
---

# EarthPress prototype build plan

**Plan, not yet built.** How to build the first proof-of-concept prototype, component by component. Building and testing to it is TRL 4 work. Decisions still to be made are kept in the design decisions register ([docs/06-design-decisions.md](06-design-decisions.md)), not here.

## 1. What you are building

Figure 1. Every component, pulled apart and numbered in build order

*Figure 1. Every component pulled apart and numbered in build order. The soil sieve, test kit and block gauge are separate and are made last.*

The prototype is one EarthPress: a welded steel press about 1.3 m long, 0.6 m wide and 1 m to the mold rim, with a removable 1.7 m lever, plus its soil sieve, soil test kit and block gauge. Figure 1 shows the 14 press components in the order you make or fit them. Thirteen are made in a welding shop: the base frame and the press core (two welded pieces that bolt together), the mold box, the lid, the piston with its push rod, four toggle links, the connecting link, the lever hub, the rest catch and end pawl, the eject seesaw, the linkage guard and the lever pipe. Bought parts are the turned pins, shaft and bushes, spacer tubes, bolts, springs and the test kit. The work is sawing, flame or plasma cutting, drilling, tapping, stick welding and grinding of mild steel plate, channel, tube and pipe. The parts cost about $523 from the bill of materials, against a value-engineering target of $500.

> **Safety:** The finished press puts 81 kN (over 8 tonne-force) on the block, and up to 173 kN if two people pull hard at the end of the stroke. Keep hands out of the mold, the linkage and the eject arm whenever anyone is on the lever. Building it involves welding, grinding and cutting: wear welding PPE, guard the grinder, and work away from anything that burns. The press weighs about 200 kg; its heaviest piece, the base frame, is 45 kg: lift every piece with two people.

## 2. What changed to make it buildable

The concept showed what the press does; some of its parts could not be made or fixed as drawn. Each change below keeps what the press does, and all of them are recorded in decision record EPR-DDR-003, accepted by Amish on 2026-10-02.

*Table 1. Changes from the concept.*

| Component | The concept had | The buildable design has | Why |
| --- | --- | --- | --- |
| Base frame | A base plate resting on nothing; cross tubes below the skid tops | Cross tubes flush with the skid tops, two of them under the base plate; a larger plate that also carries the eject posts (Figure 2) | The plate sits on, and is welded to, two tubes |
| Columns | Open side of the channel toward the mold, so the mold bolts had no room for a nut | Webs toward the mold; bolts from inside the open channel into threads tapped in the mold's flanges (Figure 8) | Every bolt can be reached with a socket |
| Base beam and lugs | Beam plates overlapping the columns; lugs floating above the beam | Beam plates on the outside of the column flanges; lugs welded between them (Figure 12) | One welded clevis for the base pin |
| Piston | A guide strap under the mold, in the path of the links at the end of the stroke | Strap removed; two end skirts under the piston keep it square in the mold (Figure 9) | Nothing in the links' path |
| Toggle pins | Pins that could not pass the column webs; links free to slide along their pins | Access holes in one column for the base pin and the upper pin; spacer tubes on the pins (Figures 10 and 12) | The pins can be fitted, and every link is located |
| Links | Bars ending at the pin centres | Round ends and pressed-in bushes on every link, with a felt or rubber dust seal washer on each outer link face (Figure 11) | Metal round every hole; grit kept out of the bushes |
| Lid hinge and latch | A hinge knuckle cutting into the mold; a latch hook that sat above its keeper | Lid ribs cut long as ears; a 30 mm hinge pin and a 30 mm latch pin through lugs on the mold (Figures 23 and 24) | Each pin works in double shear and holds the full force |
| Rest stop and end pawl | A rest bar in the lever's path; a pawl that could not reach the lever | A rest stop bar under the crank, and a spring catch and pawl that drop onto the crank pin at the start and the end of the stroke (Figures 16 and 18) | The lever cannot fall into the stroke or kick back |
| Eject lever | A fork that crossed the links at the end of the stroke | One central cranked arm whose round nose lifts the push rod's foot (Figure 20) | The arm stays inside the rod's width |
| Ties | Tubes in the crank pin's path | Tubes moved out, welded along the bracket plates, bolted to the beam (Figure 6) | The crank pin clears them |
| Linkage guard | In the parts list only | Expanded metal on an angle frame, bolted to the base and the bracket (Figure 21) | Covers the scissor points |
| Block gauge | A placeholder | Legs 292 mm apart and a 93 mm notch (Figure 26) | Checks the longest and tallest good block |

## 3. Making the components

Make and check each component before the assembly step that needs it. Sizes are in millimetres. "Front" is the side you see in Figure 1, "left" is the lever end and "right" the eject end; "+Y" is the side away from you. Workshop tolerance is 1 mm unless a step says otherwise; drawings do not carry tolerances before TRL 4. Weld with a stick welder, fillet welds the size of the thinner part, and clean off the slag before painting.

### 3.1 Base frame

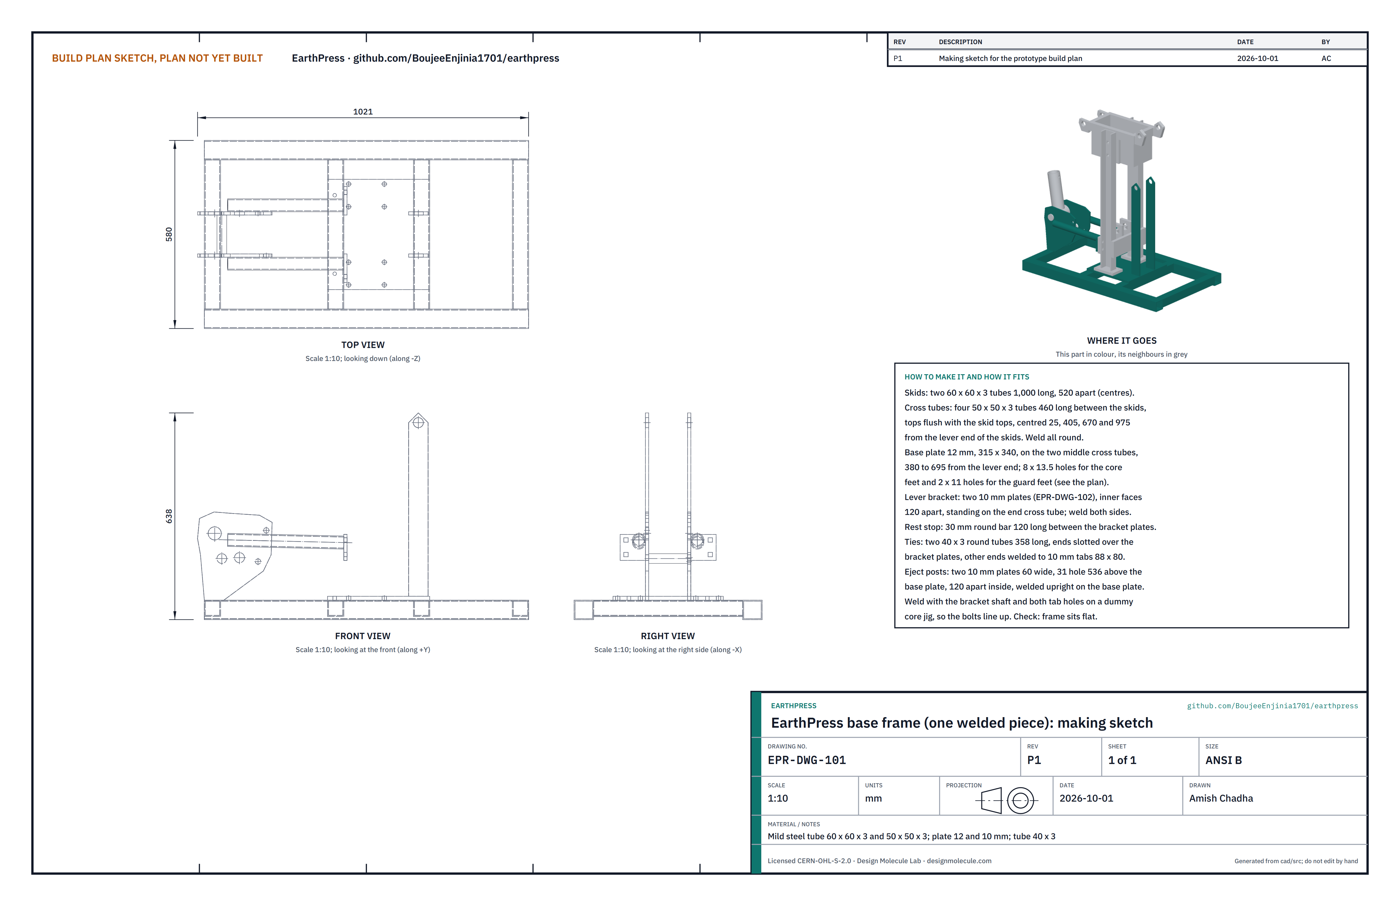
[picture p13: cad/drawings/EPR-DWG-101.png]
Figure 2. Making sketch of the base frame


*Figure 2. Base frame making sketch (EPR-DWG-101).*

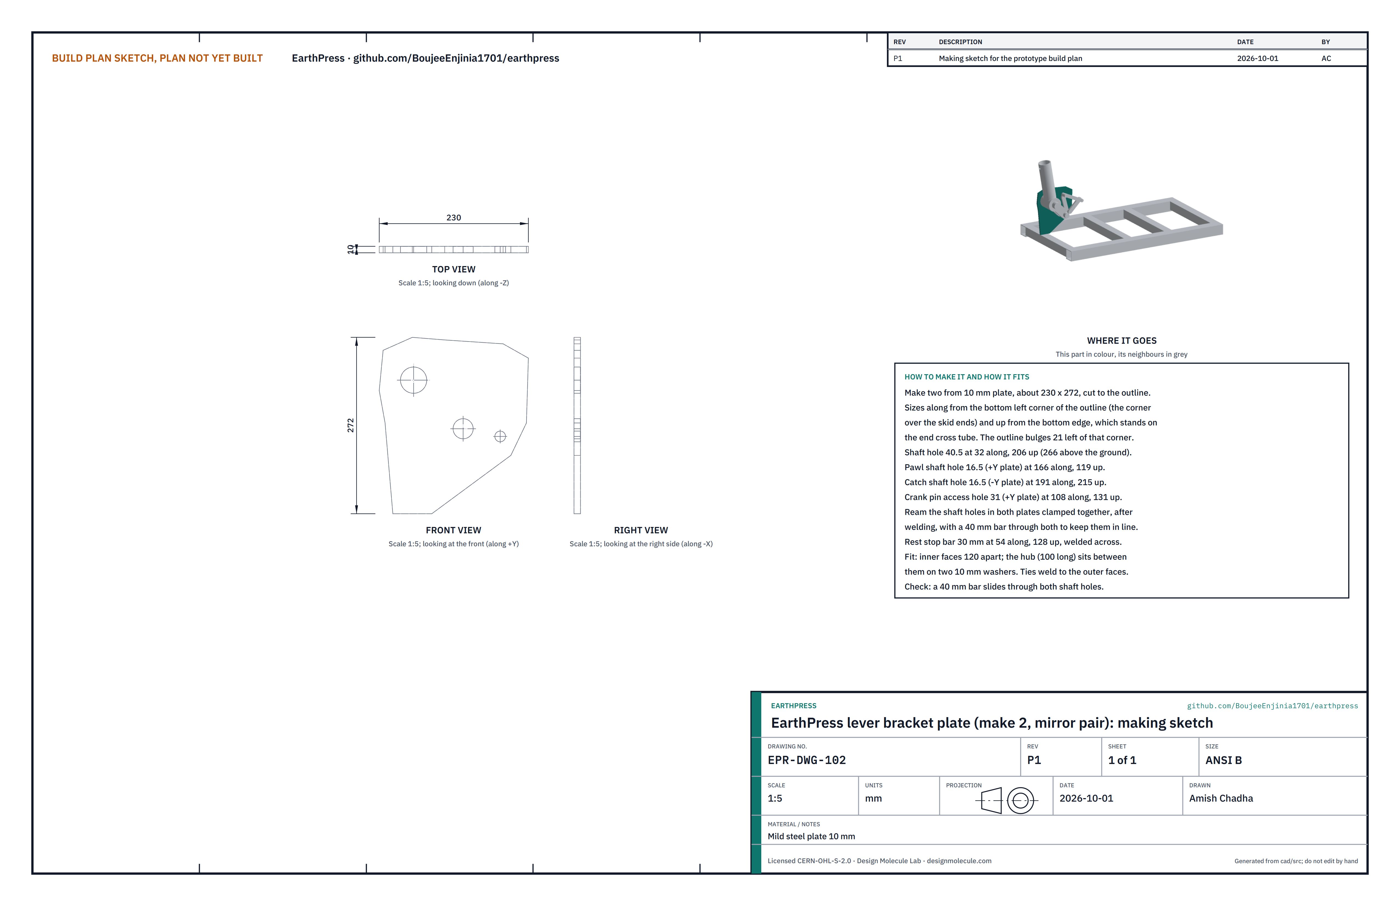
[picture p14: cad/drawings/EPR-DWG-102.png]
Figure 3. Making sketch of the lever bracket plates


*Figure 3. Lever bracket plate making sketch (EPR-DWG-102).*

**What it is and what it is made from.** The ladder frame the press stands on, with the lever bracket at the left end and the eject posts at the right: one welded piece of about 45 kg. Mild steel tube 60 x 60 x 3 and 50 x 50 x 3, plate 12 and 10 mm, round tube 40 x 3.

**How to make it.**

1. Cut two skids of 60 x 60 x 3 tube 1,000 long and four cross tubes of 50 x 50 x 3 tube 460 long.
2. Lay the skids on a flat table, 520 apart between centres. Fit the cross tubes between them with their tops flush with the skid tops, centred 25, 405, 670 and 975 from the left ends. Check the diagonals are equal, then weld all round.
3. Cut the base plate, 12 mm, 315 x 340. Drill eight 13.5 holes for the core feet (on a 110 x 70 pattern each side, centred 120 either side of the middle) and two 11 holes for the guard feet, as Figure 2 shows. Weld the plate onto the two middle cross tubes, 380 to 695 from the left ends.
4. Cut the two lever bracket plates from 10 mm plate to the outline of Figure 3 (a mirror pair). Drill the shaft hole 40.5, the pawl shaft hole 16.5 and the 31 crank pin access hole in the +Y plate, and the catch shaft hole 16.5 in the -Y plate.
5. Stand the bracket plates on the left cross tube, inner faces 120 apart, with a 40 mm bar through both shaft holes to hold them in line. Weld both sides. Weld the 30 mm rest stop bar, 120 long, across between them at the position in Figure 3, and slide on its rubber sleeve after painting.
6. Cut two 40 x 3 round tubes 358 long for the ties. Slot one end of each 10 mm wide and 40 deep so it straddles a bracket plate, and weld the other end square to a 10 mm tab 88 x 80. Drill each tab with two 13.5 holes, as Figure 6 shows.
7. Bolt the two tabs to the press core (section 3.2) as a jig, slot the tie tubes over the bracket plates, check the core stands square on the base plate, and weld the ties along the outside faces of the bracket plates. Unbolt the core.
8. Cut the two eject posts from 10 mm plate, 60 wide, with a 31 hole 536 above the bottom edge and a pointed top. Weld them upright on the base plate, 120 apart inside, centred 160 to the right of the press's centre line.

**How it fits the parts next to it.** The core's feet bolt to the base plate (Figure 5); the tie tabs bolt to the core's beam (Figure 6); the hub shaft runs through the bracket plates (Figure 16); the eject pivot pin runs through the posts (Figure 20).

**Check before moving on.** The frame sits flat on a flat floor without rocking; a 40 mm bar slides through both bracket shaft holes; the two post holes line up.

### 3.2 Press core

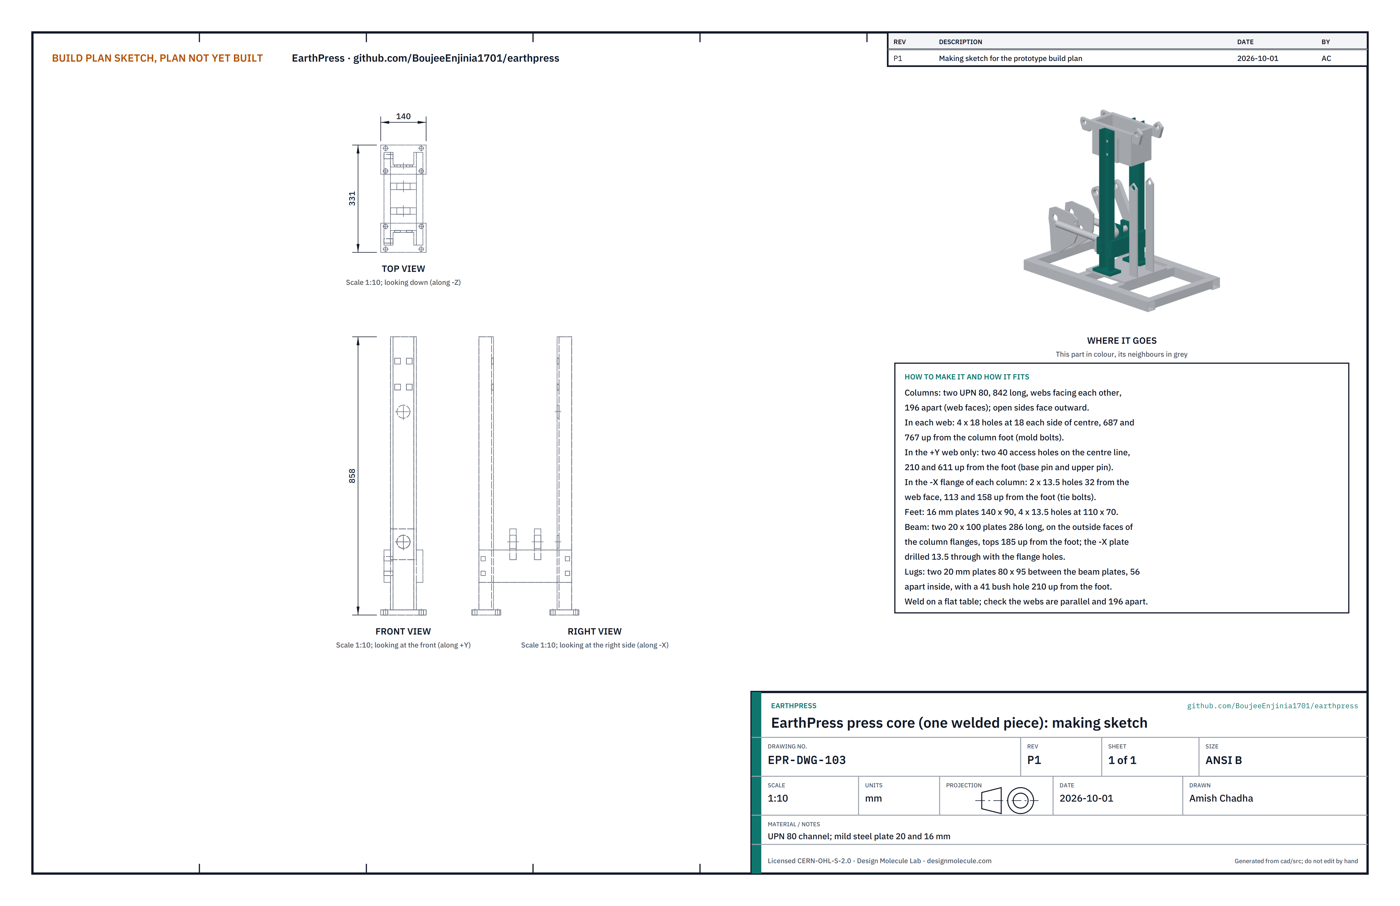
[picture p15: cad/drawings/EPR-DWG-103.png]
Figure 4. Making sketch of the press core


*Figure 4. Press core making sketch (EPR-DWG-103).*

**What it is and what it is made from.** The two columns that carry the mold, joined at the bottom by the base beam that carries the base pin: one welded piece of about 28 kg. UPN 80 channel, plate 20 and 16 mm.

**How to make it.**

1. Cut two UPN 80 columns 842 long, ends square.
2. In each web, drill four 18 holes for the mold bolts, 18 each side of the centre line, 687 and 767 up from the bottom end.
3. In one column only (the +Y column), drill two 40 access holes on the web's centre line, 210 and 611 up from the bottom end.
4. In one flange of each column (the left flange), drill two 13.5 holes 32 from the web face, 113 and 158 up from the bottom end, for the tie bolts.
5. Cut two feet, 16 mm plate 140 x 90, each drilled with four 13.5 holes on a 110 x 70 pattern. Weld a column upright on the middle of each foot, its web over the foot's long centre line.
6. Stand the two columns on a flat table with their webs facing each other, 196 apart between the web faces and square to each other.
7. Cut two beam plates, 20 x 100 x 286. Clamp one to the outside faces of the left flanges, top edge 185 above the feet, and drill through the 13.5 tie bolt holes. Weld both beam plates to the outside faces of the flanges.
8. Cut two lugs, 20 mm plate 80 x 95, with a 41 hole 55 from the top edge. Fit them between the beam plates, 56 apart inside, with a 41 bar through both holes to hold them in line, 210 above the feet, and weld them to both beam plates.

**How it fits the parts next to it.**

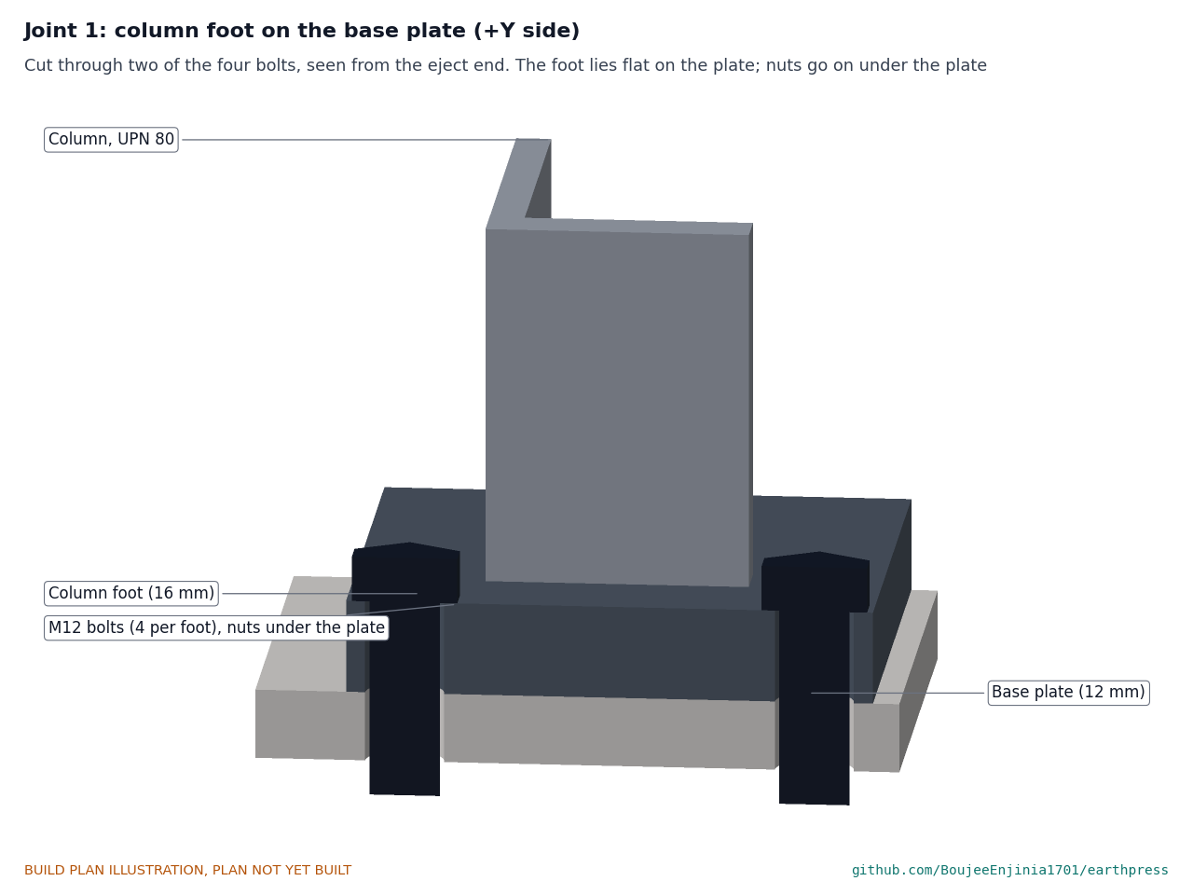
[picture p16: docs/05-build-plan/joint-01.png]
Figure 5. Joint 1: column foot on the base plate


*Figure 5. Joint 1: each foot lies flat on the base plate, held by four M12 bolts with the nuts under the plate.*

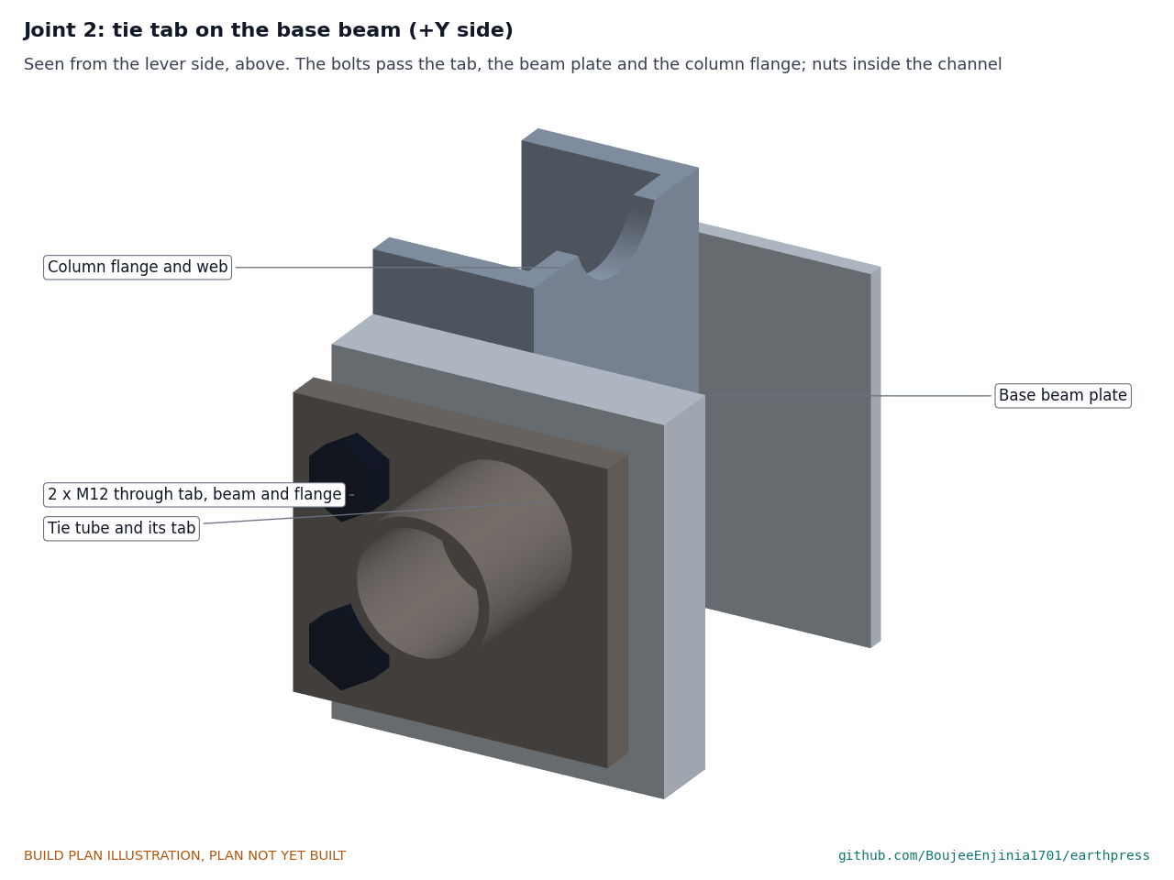
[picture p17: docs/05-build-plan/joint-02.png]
Figure 6. Joint 2: tie tab on the base beam


*Figure 6. Joint 2: two M12 bolts pass through the tie's tab, the beam plate and the column flange; the nuts go on inside the open channel.*

**Check before moving on.** The webs are parallel and 196 apart (plus 0.5, minus 0) at top and bottom; a 41 bar slides through both lugs.

### 3.3 Mold box

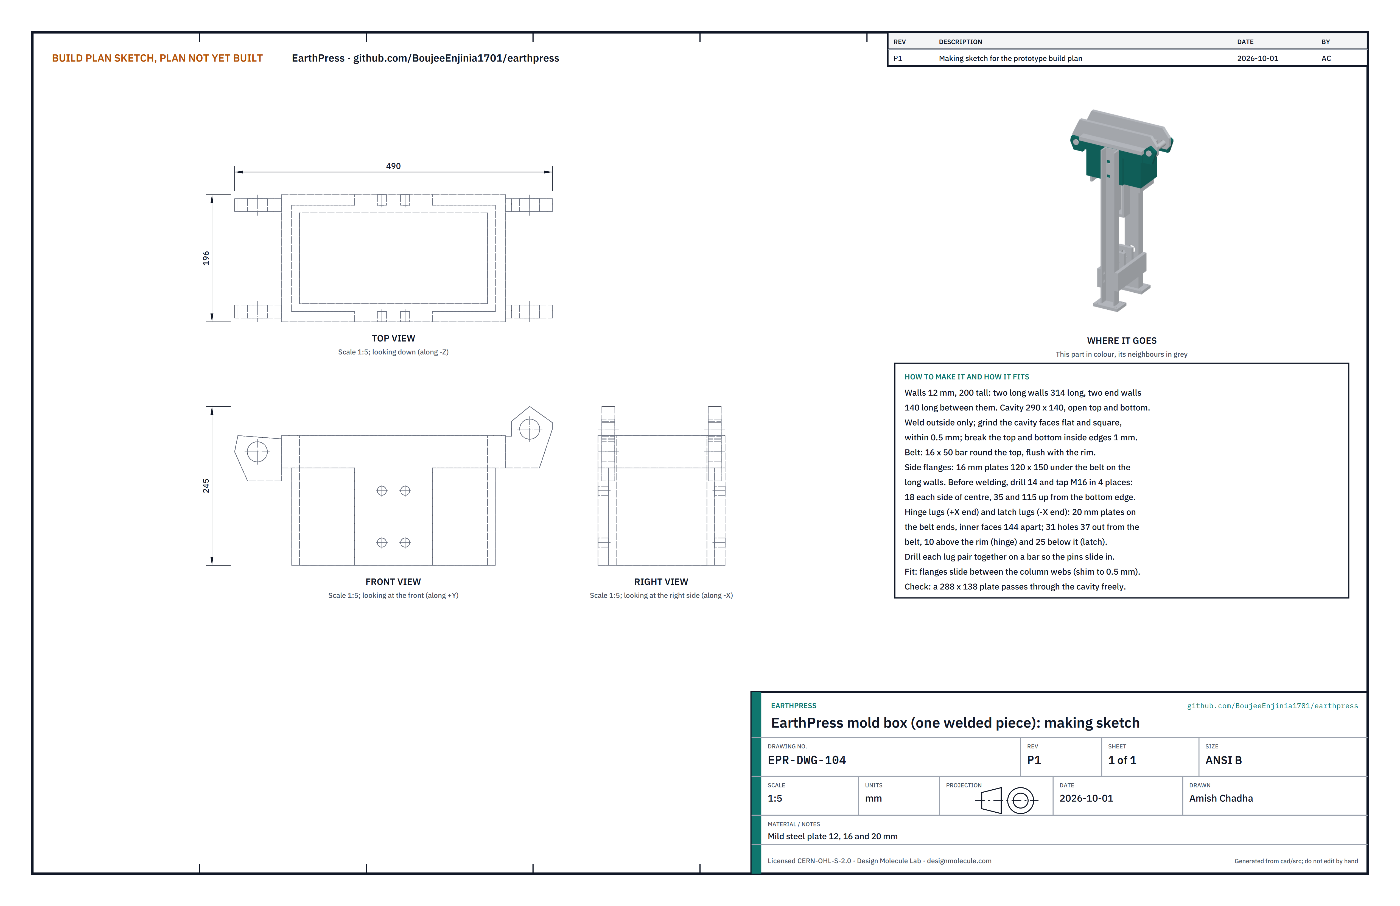
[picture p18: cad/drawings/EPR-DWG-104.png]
Figure 7. Making sketch of the mold box


*Figure 7. Mold box making sketch (EPR-DWG-104).*

**What it is and what it is made from.** The open box the soil is pressed in, with a stiffening belt round its top, two side flanges that bolt to the columns, and lugs for the lid's hinge and latch pins: one welded piece of about 30 kg. Mild steel plate 12, 16 and 20 mm, and 16 x 50 bar.

**How to make it.**

1. Cut two long walls 314 x 200 and two end walls 140 x 200 from 12 mm plate. Mark the inside faces.
2. Tack the box together on a flat plate with the end walls between the long walls, check the cavity is 290 x 140 and square, and weld outside only.
3. Grind the four inside faces flat and square within 0.5 mm and break the inside edges at top and bottom by 1 mm.
4. Cut two side flanges, 16 mm plate 120 x 150. Before welding, drill 14 and tap M16 in four places: 18 each side of the centre, 35 and 115 up from the bottom edge.
5. Weld the 16 x 50 belt round the top, flush with the rim, then the flanges centred on the long walls under the belt.
6. Cut four lugs from 20 mm plate (Figure 7). Drill each pair together with a 31 drill on one bar. Weld the hinge lugs to the right end of the belt and the latch lugs to the left end, inner faces 144 apart, with a 30 bar through each pair so the holes stay in line: the hinge holes 37 out from the belt and 10 above the rim, the latch holes 37 out and 25 below the rim.

**How it fits the parts next to it.**

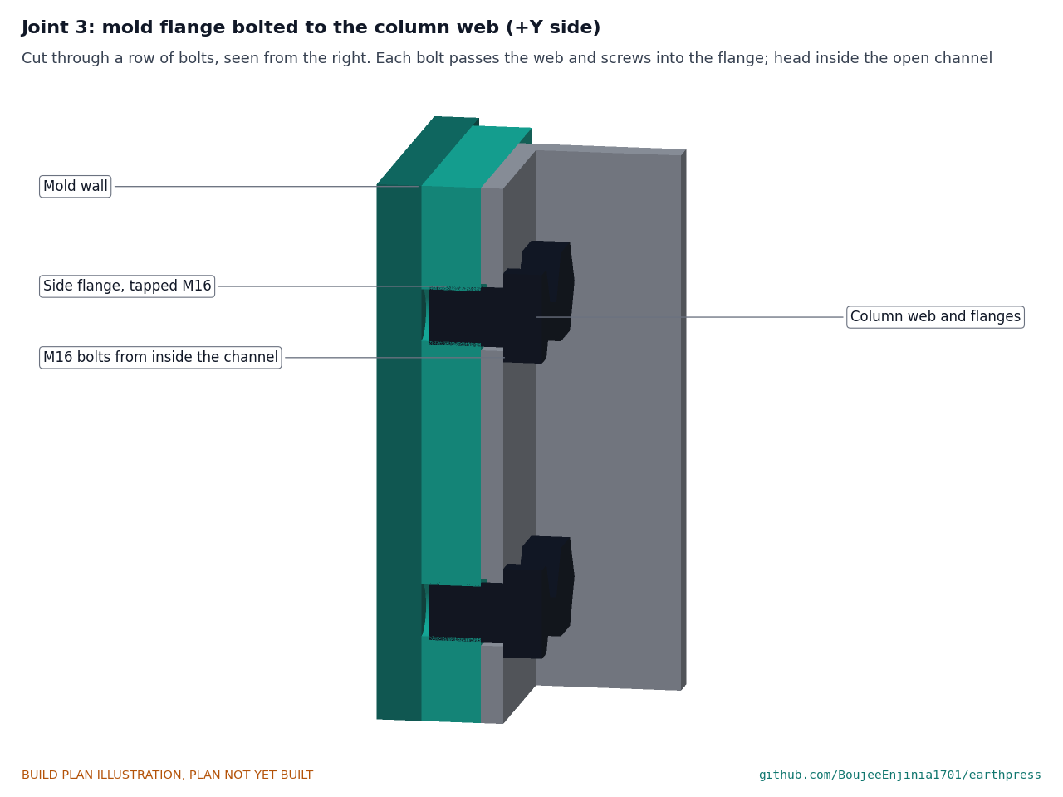
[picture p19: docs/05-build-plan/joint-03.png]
Figure 8. Joint 3: mold flange bolted to the column web


*Figure 8. Joint 3: the flange lies flat against the column web; four M16 bolts go through the web from inside the channel into the tapped flange.*

The flanges slide between the two column webs; shim to a gap of 0.5 mm or less. The rim sits 940 above the ground.

**Check before moving on.** A 288 x 138 plate passes through the cavity without catching; both pin bars slide through their lugs.

### 3.4 Piston and push rod

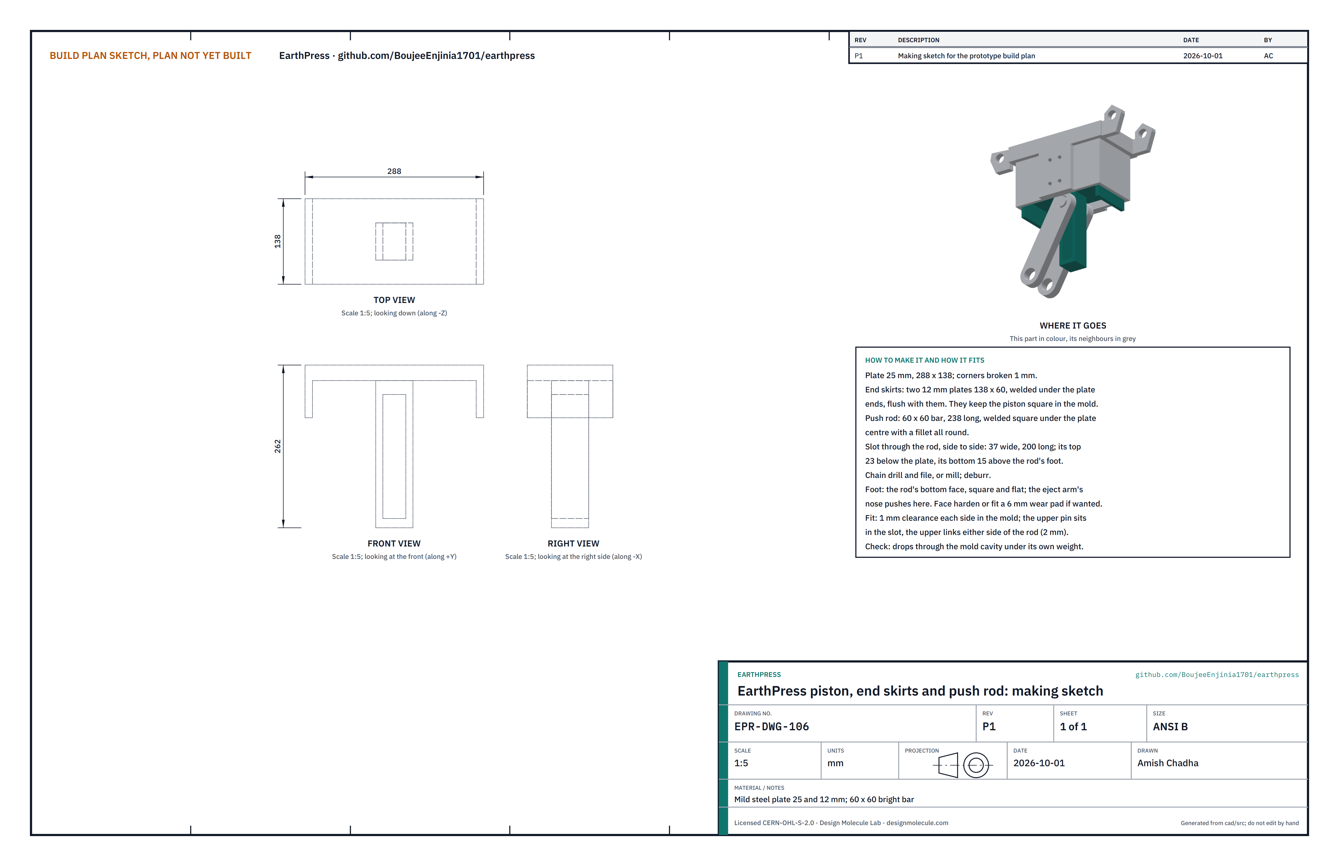
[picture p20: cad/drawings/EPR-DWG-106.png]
Figure 9. Making sketch of the piston and push rod


*Figure 9. Piston making sketch (EPR-DWG-106).*

**What it is and what it is made from.** The plate that presses the soil, with two end skirts that keep it square in the mold, on a square push rod slotted for the upper toggle pin. One welded piece of about 13 kg. Plate 25 and 12 mm, 60 x 60 bright bar.

**How to make it.**

1. Cut the plate, 25 mm, 288 x 138, and break its edges 1 mm.
2. Cut two skirts, 12 mm plate 138 x 60, and weld them under the plate's two short ends, flush with the ends.
3. Cut the push rod, 60 x 60 bar, 238 long. Cut the slot through it, side to side: 37 wide and 200 long, its top 23 below the plate and its bottom 15 above the rod's foot. Chain drill and file, or mill. Deburr.
4. Weld the rod square under the plate's centre, slot running across the press, with a fillet all round. Check it is square to the plate within 0.5 mm over its length.
5. Grind the rod's foot flat and square: the eject arm pushes on it.

**How it fits the parts next to it.**

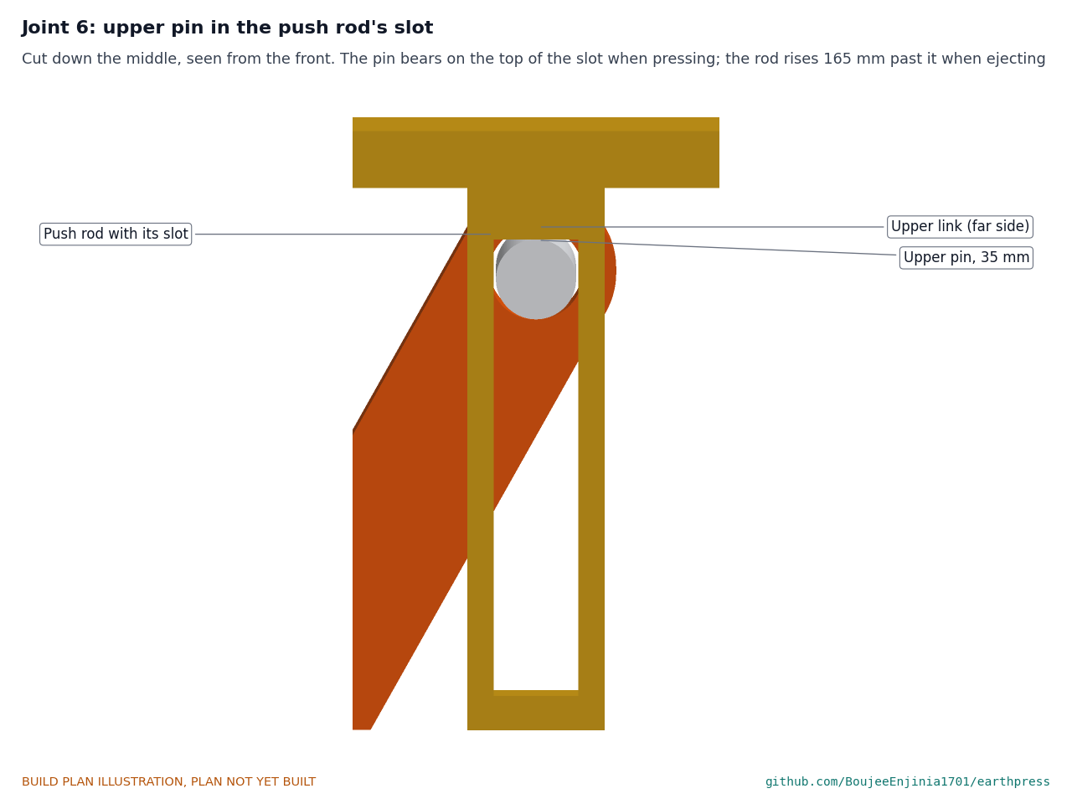
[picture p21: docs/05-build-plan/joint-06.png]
Figure 10. Joint 6: the upper pin in the push rod's slot


*Figure 10. Joint 6: the upper pin sits in the slot with the upper links either side of the rod; the pin pushes on the top of the slot when pressing, and the rod rises past it when ejecting.*

The piston has 1 mm clearance each side in the mold; the upper links pass 2 mm from the rod's sides.

**Check before moving on.** The piston drops through the mold cavity under its own weight in either direction.

### 3.5 Toggle links (make 4)

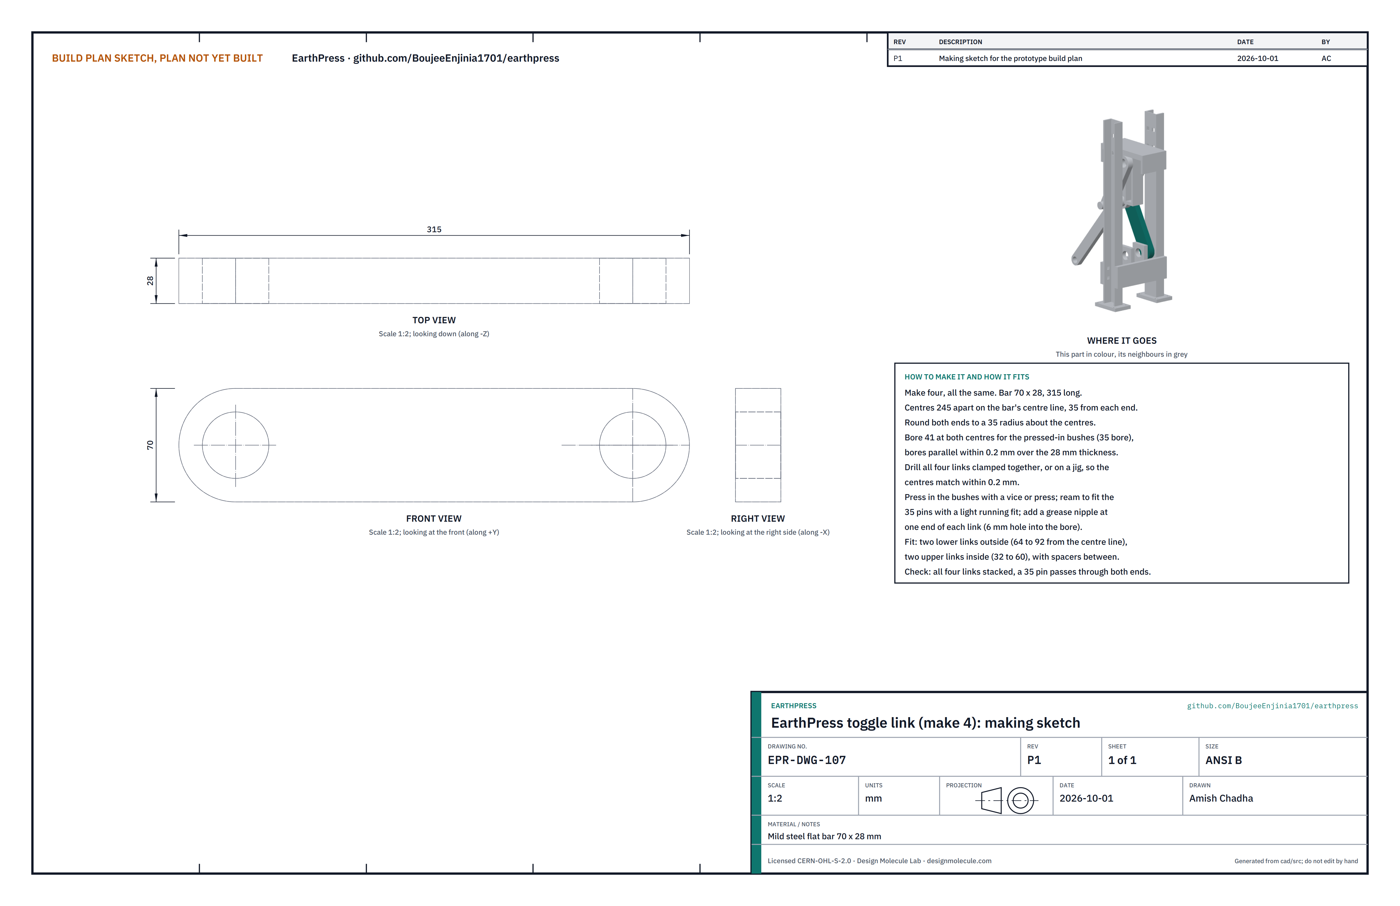
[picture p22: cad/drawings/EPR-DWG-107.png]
Figure 11. Making sketch of the toggle link


*Figure 11. Toggle link making sketch (EPR-DWG-107).*

**What it is and what it is made from.** The four links that straighten under the piston and multiply the lever's force. Mild steel flat bar 70 x 28, with pressed-in case-hardened bushes, 35 bore and 41 outside.

**How to make it.**

1. Cut four lengths of 70 x 28 bar, 315 long.
2. Clamp all four together, mark two centres 245 apart on the centre line, 35 from each end, and drill and bore 41 through all four at once, square to the faces.
3. Round both ends to a 35 radius about the centres.
4. Press a bush into each bore with a vice or press. Drill a 6 hole from the edge into one bore of each link and fit a grease nipple.
5. Ream the bushes to a light running fit on the 35 pins.
6. Cut or buy eight dust seal washers, 2 thick, 50 outside and 35.5 bore, from felt or rubber sheet (the toggle needs eight in all).

**How it fits the parts next to it.**

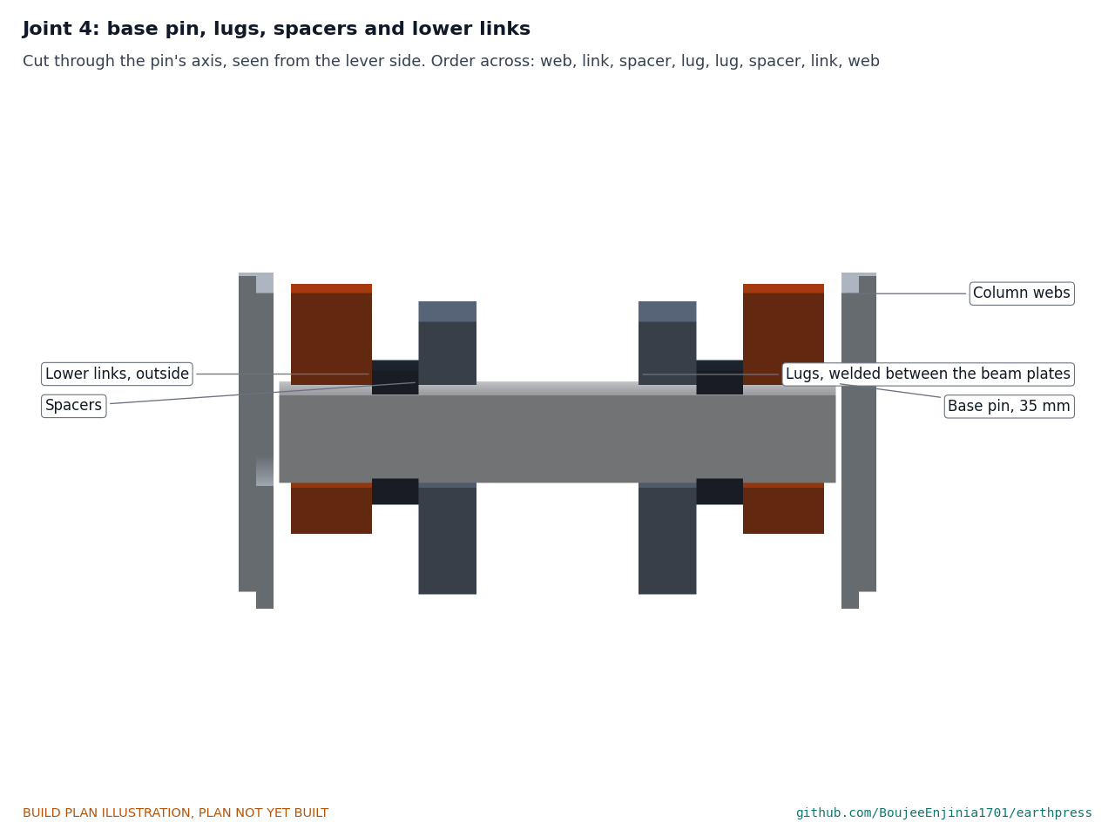
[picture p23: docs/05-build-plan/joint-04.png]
Figure 12. Joint 4: base pin, lugs, spacers and lower links


*Figure 12. Joint 4, cut through the pin: across the press the order is column web, lower link, spacer, lug, lug, spacer, lower link, column web.*

Two links are the lower links, outside, from 64 to 92 off the centre line; two are the upper links, inside, from 32 to 60.

**Check before moving on.** With all four links stacked, a 35 pin passes through both ends.

### 3.6 Connecting link

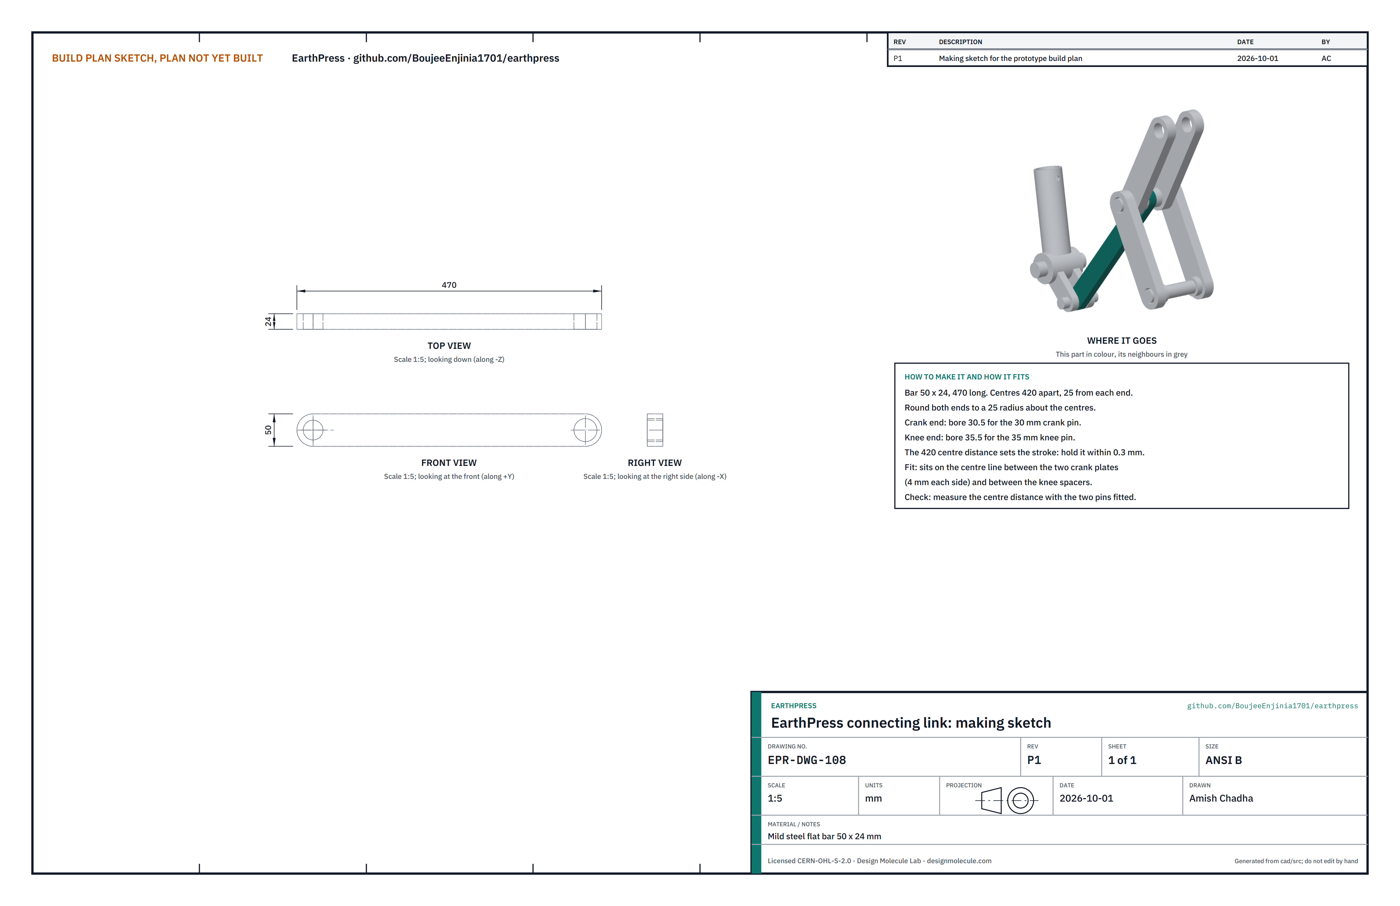
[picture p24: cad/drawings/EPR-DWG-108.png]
Figure 13. Making sketch of the connecting link


*Figure 13. Connecting link making sketch (EPR-DWG-108).*

**What it is and what it is made from.** The link from the crank on the lever hub to the toggle's knee. Mild steel flat bar 50 x 24.

**How to make it.**

1. Cut 470 long. Mark two centres 420 apart on the centre line, 25 from each end; hold 420 within 0.3, since it sets the stroke.
2. Bore 30.5 at the crank end and 35.5 at the knee end. Round both ends to a 25 radius.

**How it fits the parts next to it.**

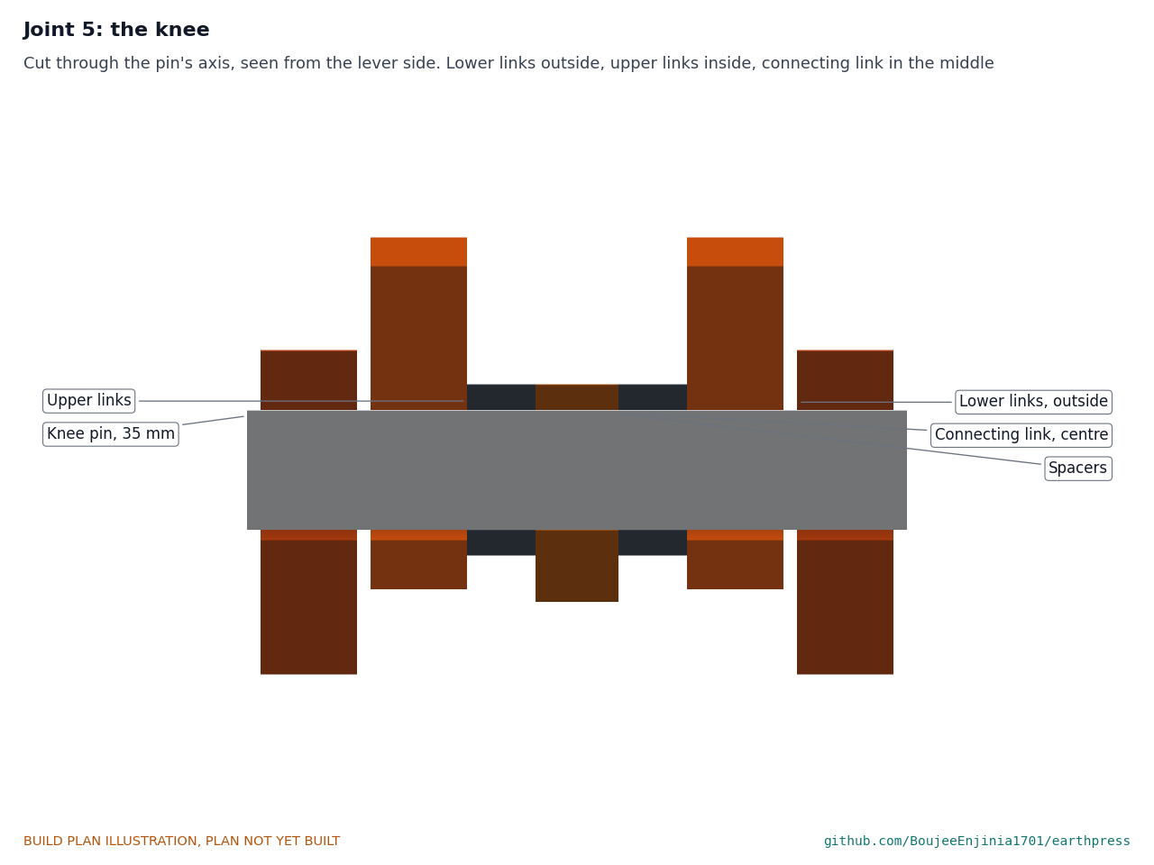
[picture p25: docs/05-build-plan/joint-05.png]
Figure 14. Joint 5: the knee


*Figure 14. Joint 5, cut through the knee pin: lower links outside, upper links inside, the connecting link in the middle between two spacers.*

At the crank end it sits on the centre line between the two crank plates, 4 mm from each.

**Check before moving on.** With both pins fitted, the centre distance is 420 within 0.3.

### 3.7 Lever hub, crank plates and socket

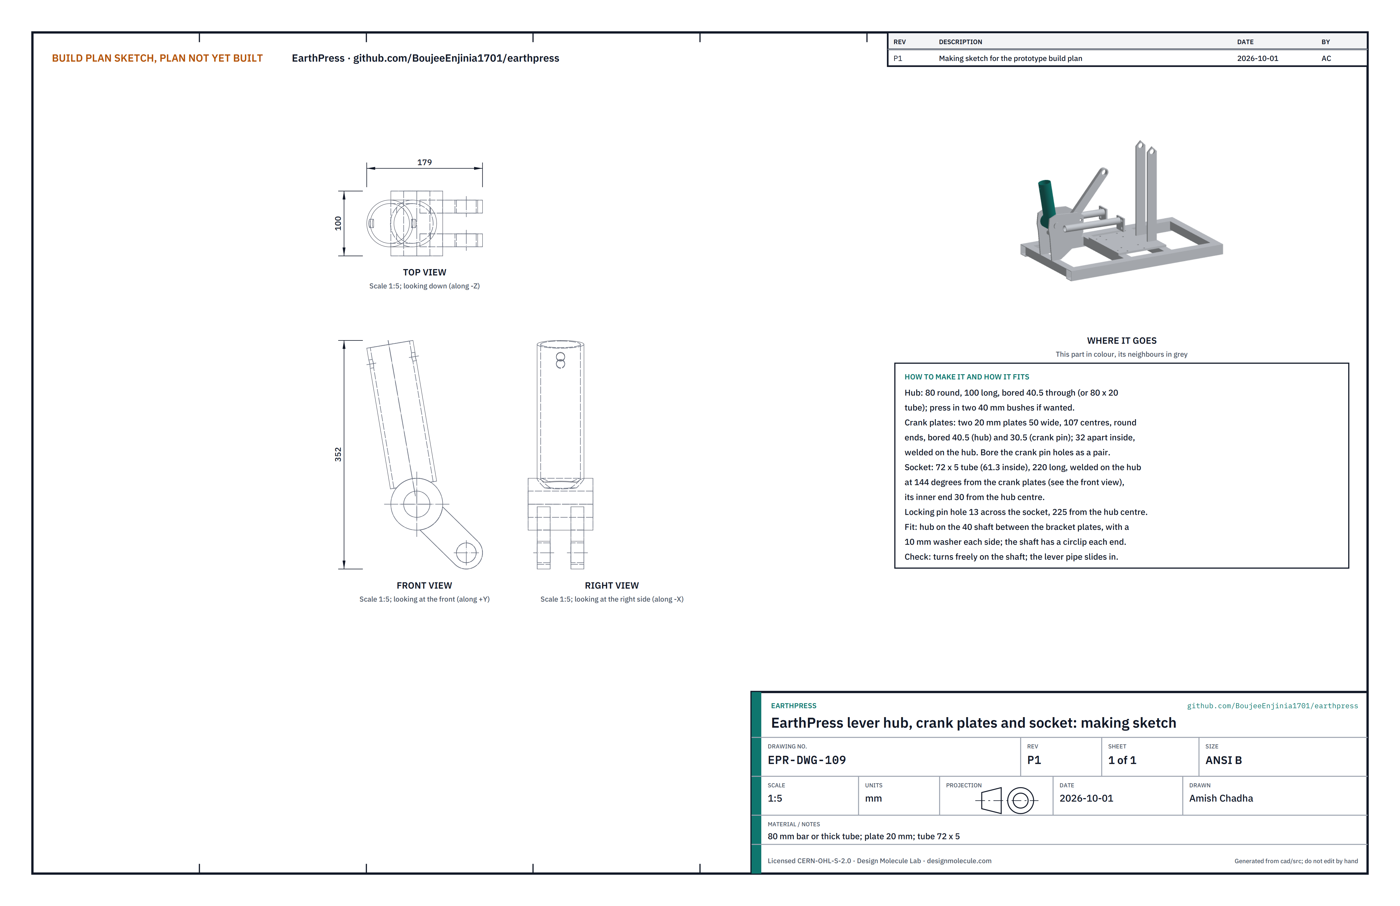
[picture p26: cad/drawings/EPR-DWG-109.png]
Figure 15. Making sketch of the lever hub


*Figure 15. Lever hub making sketch (EPR-DWG-109).*

**What it is and what it is made from.** The hub that turns on its shaft in the bracket, carrying the two crank plates and the socket for the lever. One welded piece. 80 round bar (or 80 x 20 thick tube), plate 20 mm, tube 72 x 5.

**How to make it.**

1. Cut the hub 100 long from 80 bar and bore it 40.5 through (or fit two 40 bore bushes).
2. Cut two crank plates from 20 mm plate, 50 wide with round ends, 107 between centres. Clamp them together and bore 40.5 (hub end) and 30.5 (crank pin end).
3. Slide the crank plates over a 40 bar through the hub, 32 apart inside, and weld them to the hub.
4. Cut the socket, 72 x 5 tube, 220 long. Weld it to the hub at 144° from the crank plates, measured as in Figure 15, its inner end 30 from the hub centre.
5. Drill a 13 hole across the socket, 225 from the hub centre, for the locking pin.

**How it fits the parts next to it.**

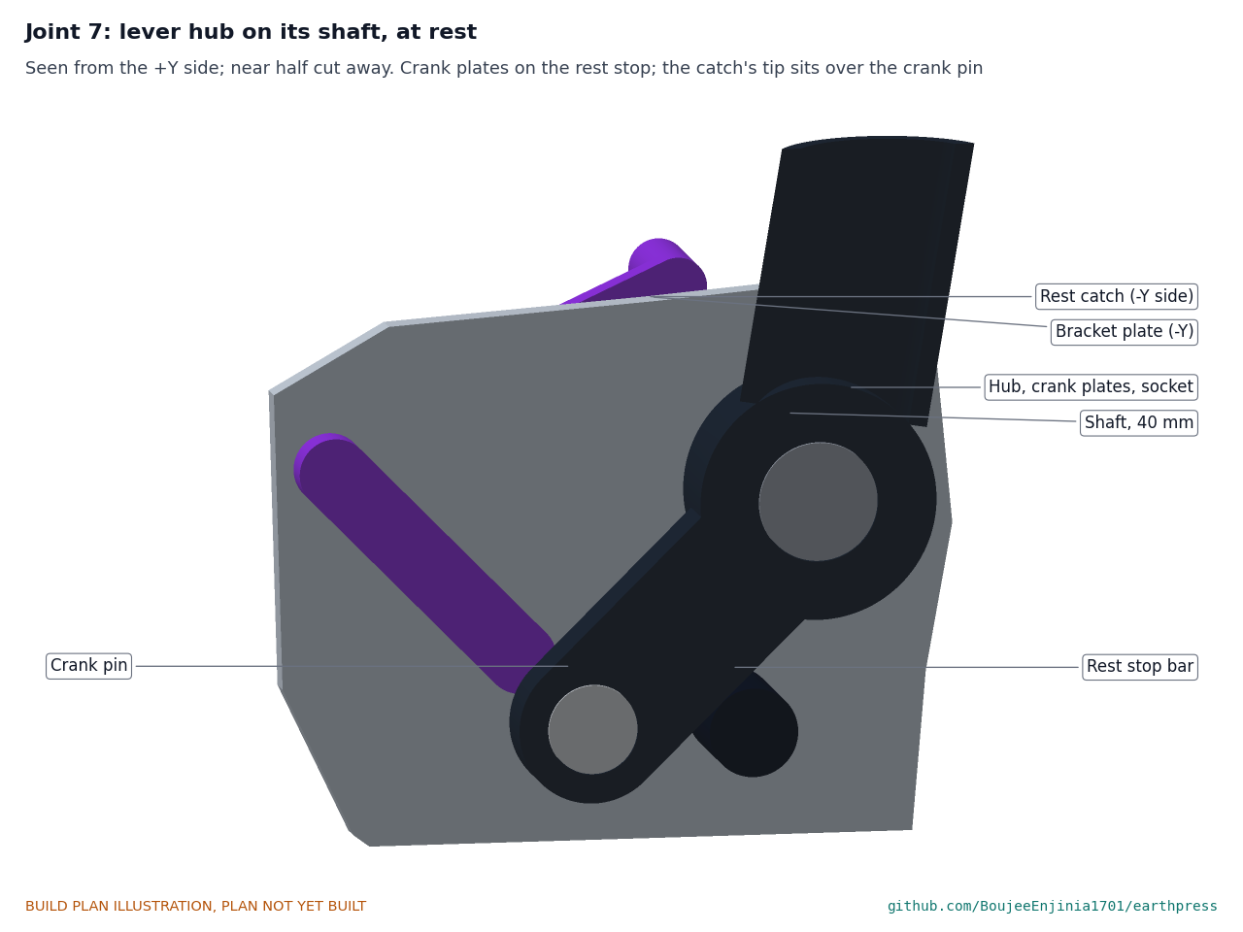
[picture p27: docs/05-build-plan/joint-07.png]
Figure 16. Joint 7: the lever hub on its shaft, at rest


*Figure 16. Joint 7: the hub turns on the 40 shaft between the bracket plates, with a 10 mm washer each side; at rest the crank plates lie on the rest stop bar and the catch sits over the crank pin.*

**Check before moving on.** The hub turns freely on a 40 bar; the lever pipe slides into the socket.

### 3.8 Rest catch and end pawl (one of each)

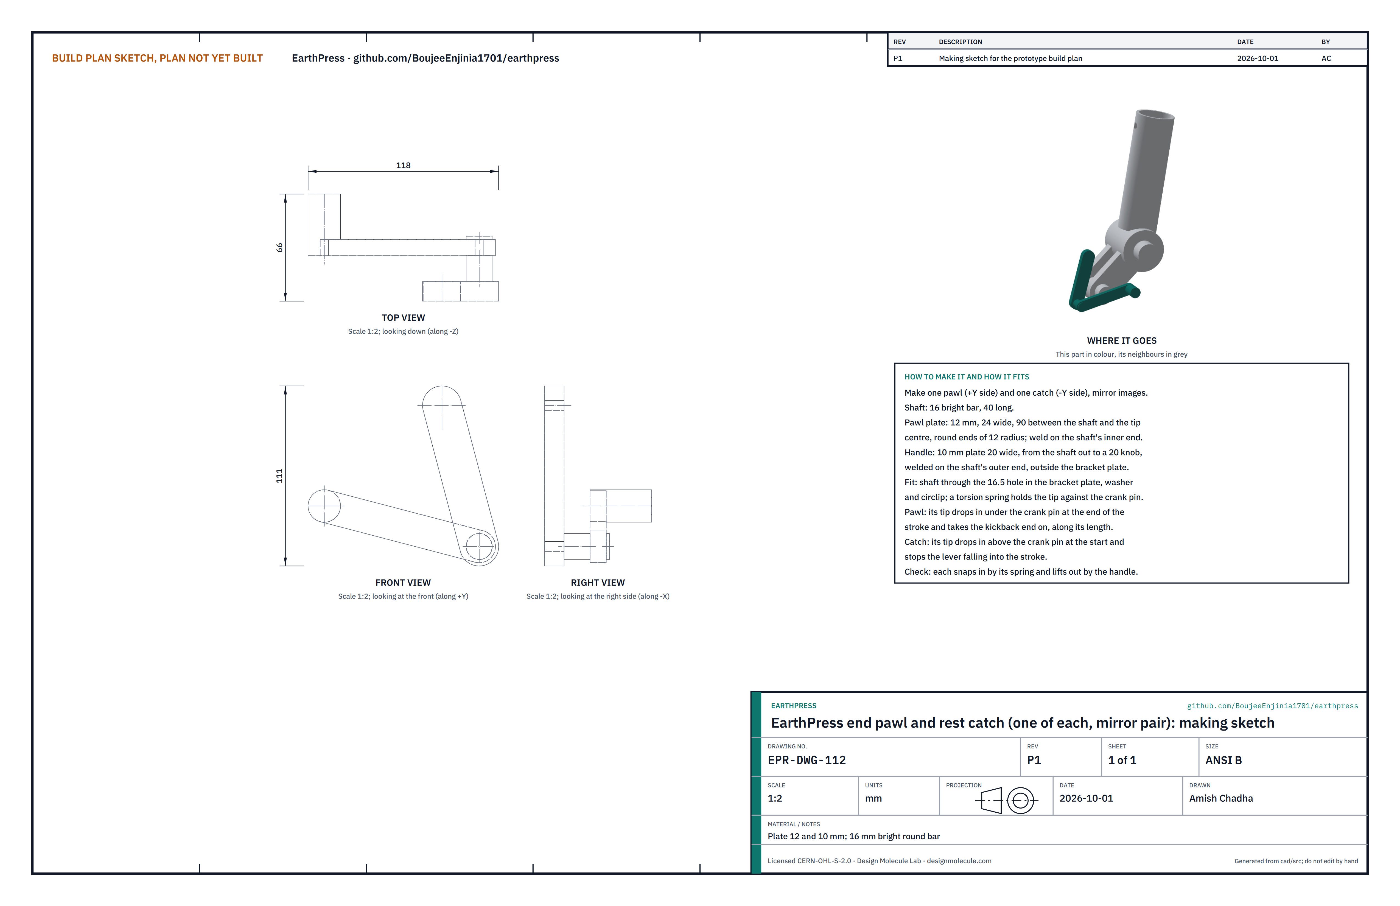
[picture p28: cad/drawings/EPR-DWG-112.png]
Figure 17. Making sketch of the end pawl and rest catch


*Figure 17. End pawl and rest catch making sketch (EPR-DWG-112).*

**What it is and what it is made from.** Two spring pawls, mirror images, that catch the crank pin: the rest catch (on the -Y bracket plate) holds the lever at the start of the stroke, and the end pawl (on the +Y plate) holds it at the end. Plate 12 and 10 mm, 16 bright round bar.

**How to make it.**

1. For each: cut a 16 bar shaft 40 long; a pawl plate, 12 mm, 24 wide, with round ends of 12 radius and 90 between the shaft centre and the tip centre; and a handle plate, 10 mm, 20 wide, from the shaft to a 20 round knob.
2. Weld the pawl plate on one end of the shaft and, after fitting the shaft through its bracket plate, the handle on the other end, so the handle lies outside the bracket.
3. Round and smooth the tip; it slides on the crank pin.

**How it fits the parts next to it.**

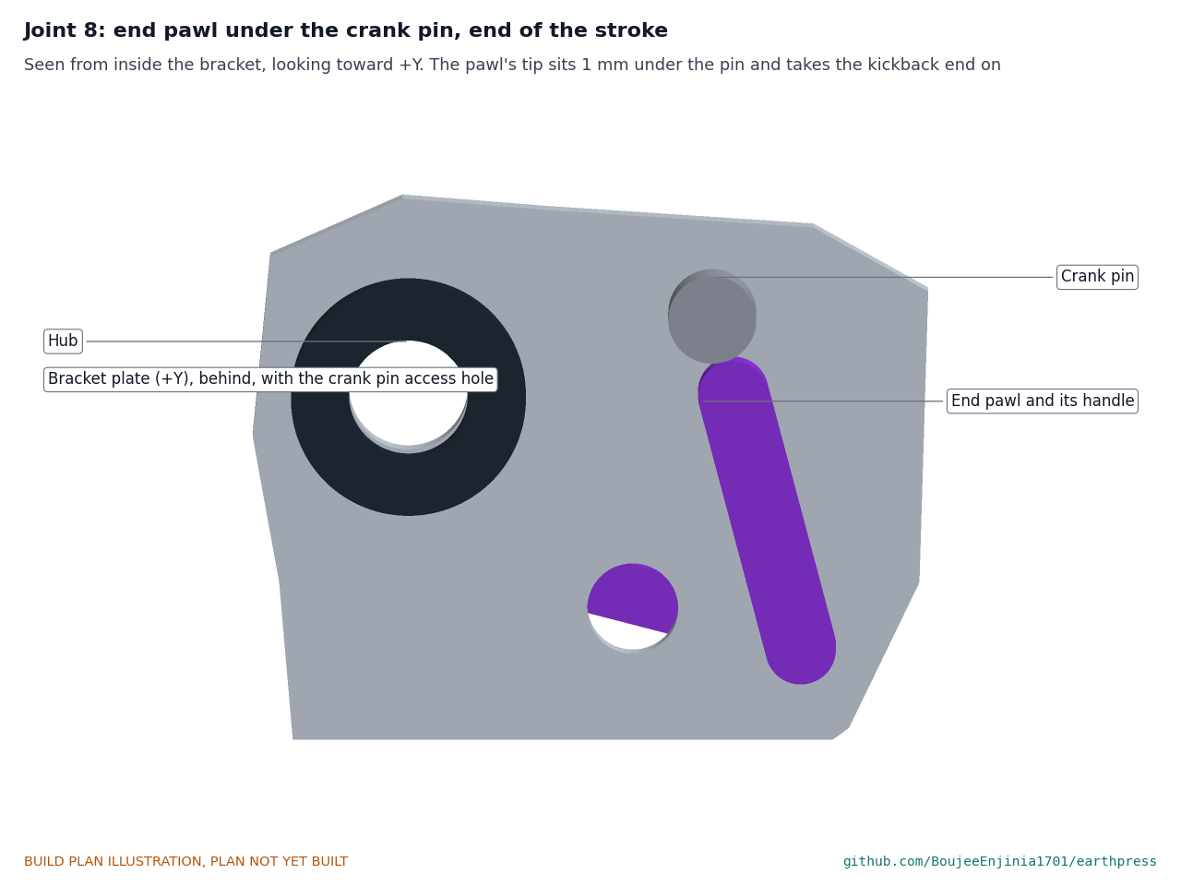
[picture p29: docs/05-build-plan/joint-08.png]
Figure 18. Joint 8: the end pawl under the crank pin


*Figure 18. Joint 8, at the end of the stroke: the pawl's tip sits 1 mm under the crank pin; if the lever is let go, the pin pushes the pawl end on, toward its shaft.*

A washer and circlip hold each shaft; a torsion spring holds the tip against the crank pin. The crank pin pushes each one aside as it passes; the catch drops in over the pin when the lever comes back to rest, and the pawl drops in under it at the end of the stroke.

**Check before moving on.** Each turns freely in its hole, snaps back on its spring and lifts clear with the handle.

### 3.9 Eject seesaw

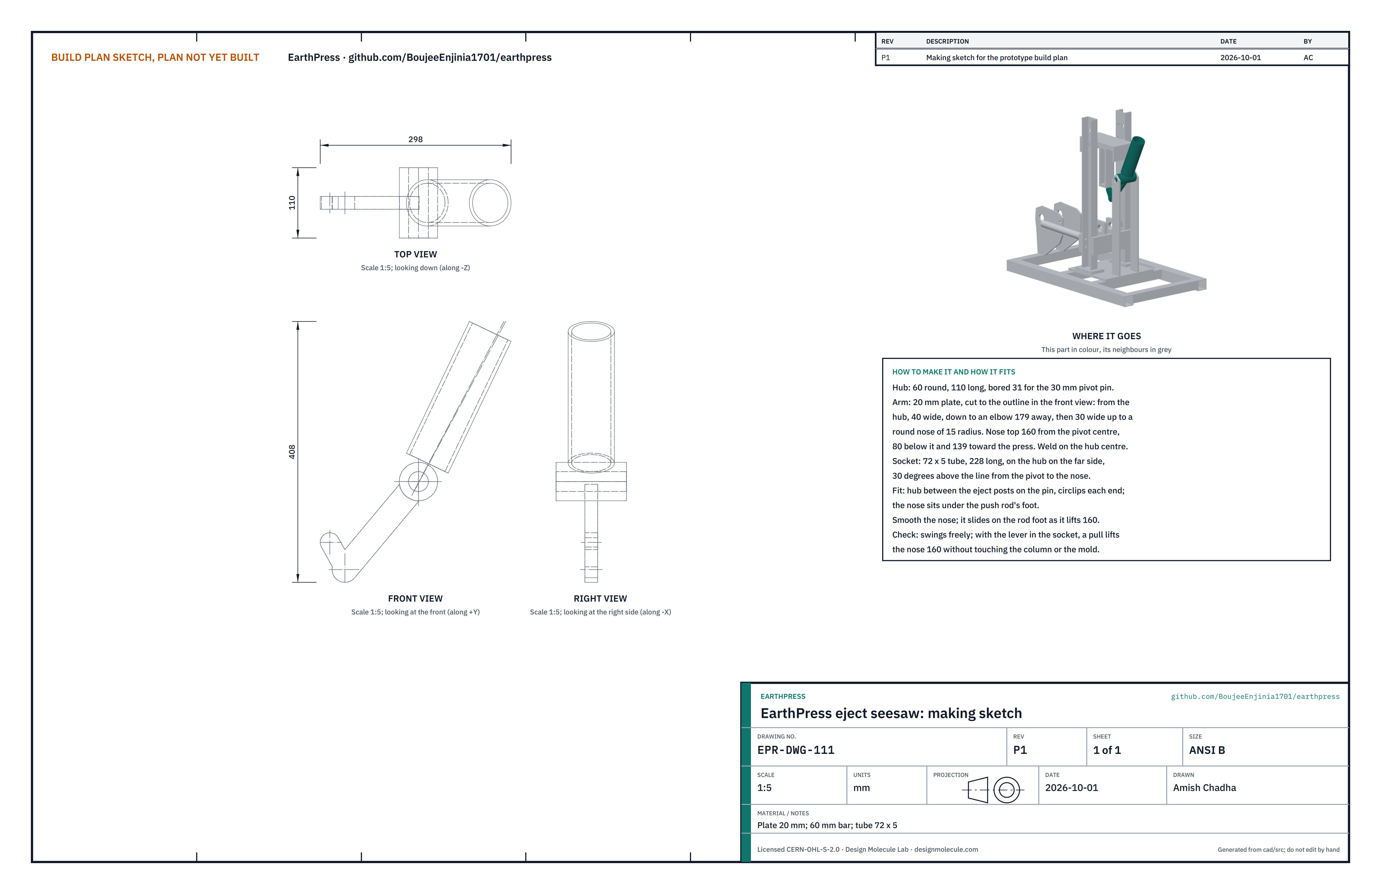
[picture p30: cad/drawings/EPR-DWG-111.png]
Figure 19. Making sketch of the eject seesaw


*Figure 19. Eject seesaw making sketch (EPR-DWG-111).*

**What it is and what it is made from.** The seesaw on the right of the press: the lever, moved into its socket, swings the arm's round nose up under the push rod's foot to lift the block out. One welded piece. Plate 20 mm, 60 round bar, tube 72 x 5.

**How to make it.**

1. Cut the hub 110 long from 60 bar and bore it 31.
2. Cut the arm from 20 mm plate to the outline in Figure 19: 40 wide from the hub down to the elbow, then 30 wide up to a round nose of 15 radius. The top of the nose is 160 from the hub centre, 80 below it and 139 toward the press.
3. Weld the arm on the middle of the hub. Weld the socket, 72 x 5 tube 228 long, on the hub on the far side, 30° above the line from the hub to the nose.
4. Smooth and round the nose.

**How it fits the parts next to it.**

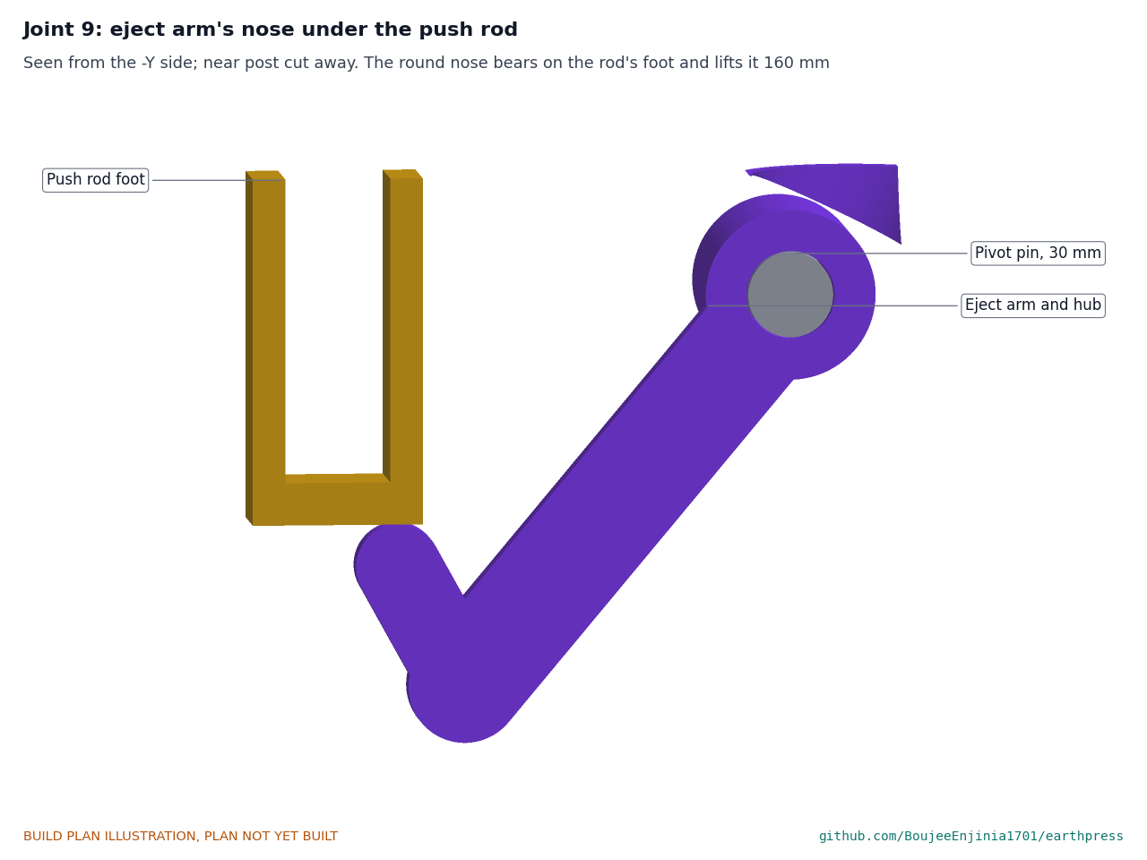
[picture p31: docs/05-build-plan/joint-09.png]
Figure 20. Joint 9: the eject arm's nose under the push rod


*Figure 20. Joint 9: the hub turns on a 30 pin between the eject posts; the round nose bears on the push rod's foot and slides on it as it lifts 160.*

**Check before moving on.** The seesaw swings freely on the pin.

### 3.10 Linkage guard

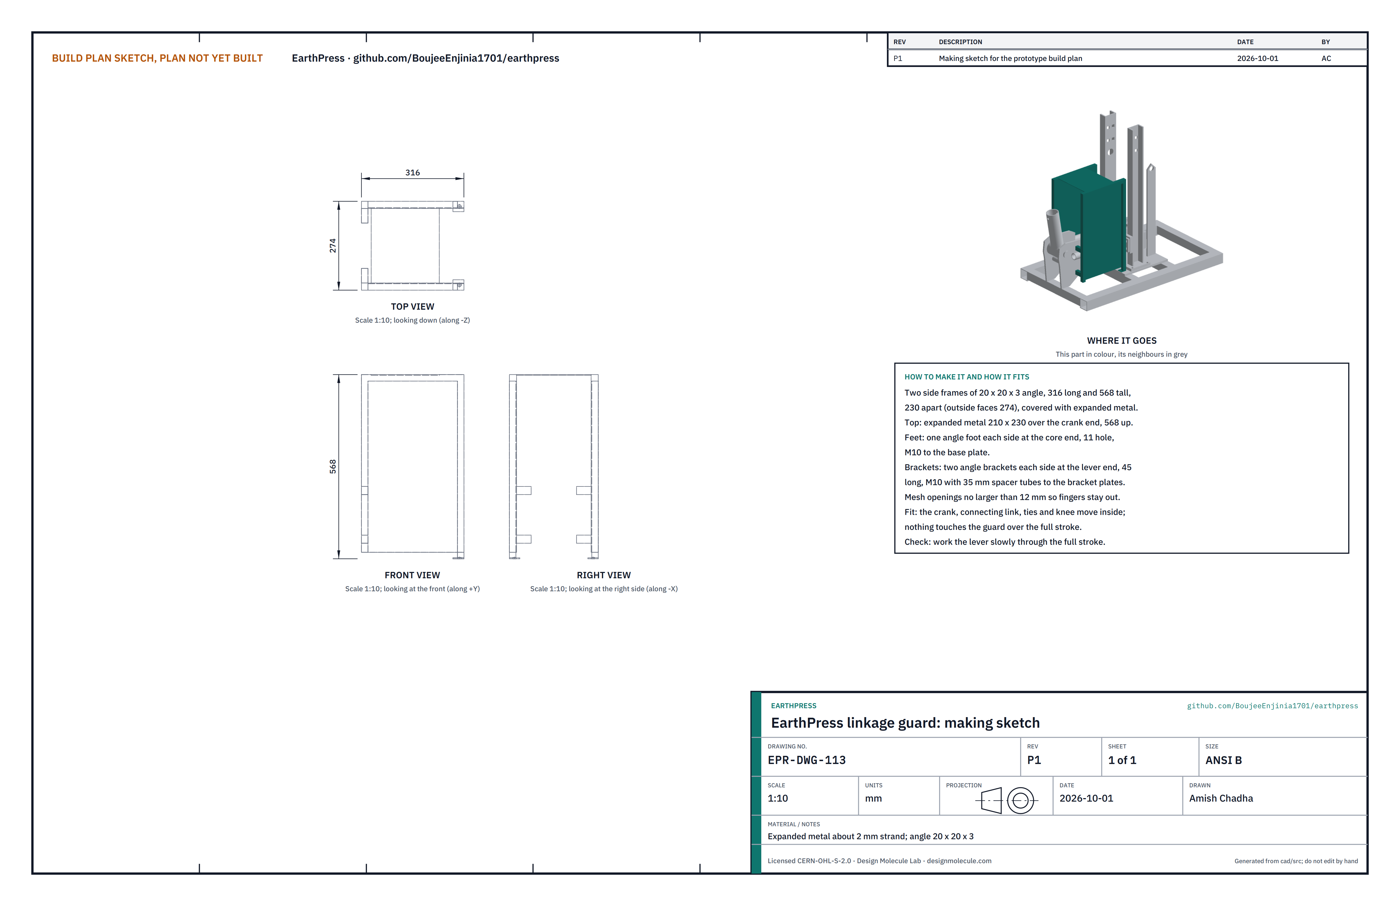
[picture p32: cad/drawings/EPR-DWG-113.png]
Figure 21. Making sketch of the linkage guard


*Figure 21. Linkage guard making sketch (EPR-DWG-113).*

**What it is and what it is made from.** A cover over the crank, connecting link, ties and knee, so no hand can reach the scissor points. Expanded metal (about 2 mm strand, openings 12 mm or smaller) on a 20 x 20 x 3 angle frame.

**How to make it.**

1. Make two side frames of angle, 316 long and 568 tall, and join them at the top with angle so their outside faces are 274 apart.
2. Cover both sides, and the top over the left 210, with expanded metal; weld or bolt it to the frame.
3. Weld an angle foot with an 11 hole at the bottom right corner of each side, and two short angle brackets near the left end of each side, each with an 11 hole for an M10 bolt and a 35 mm spacer tube.

**How it fits the parts next to it.** The feet bolt to the base plate with M10; the brackets bolt to the bracket plates' outside faces with M10 through 35 mm spacers. Nothing that moves touches the guard over the full stroke.

**Check before moving on.** No opening larger than 12 mm; no sharp wire ends.

### 3.11 Lid with ribs and pin ears

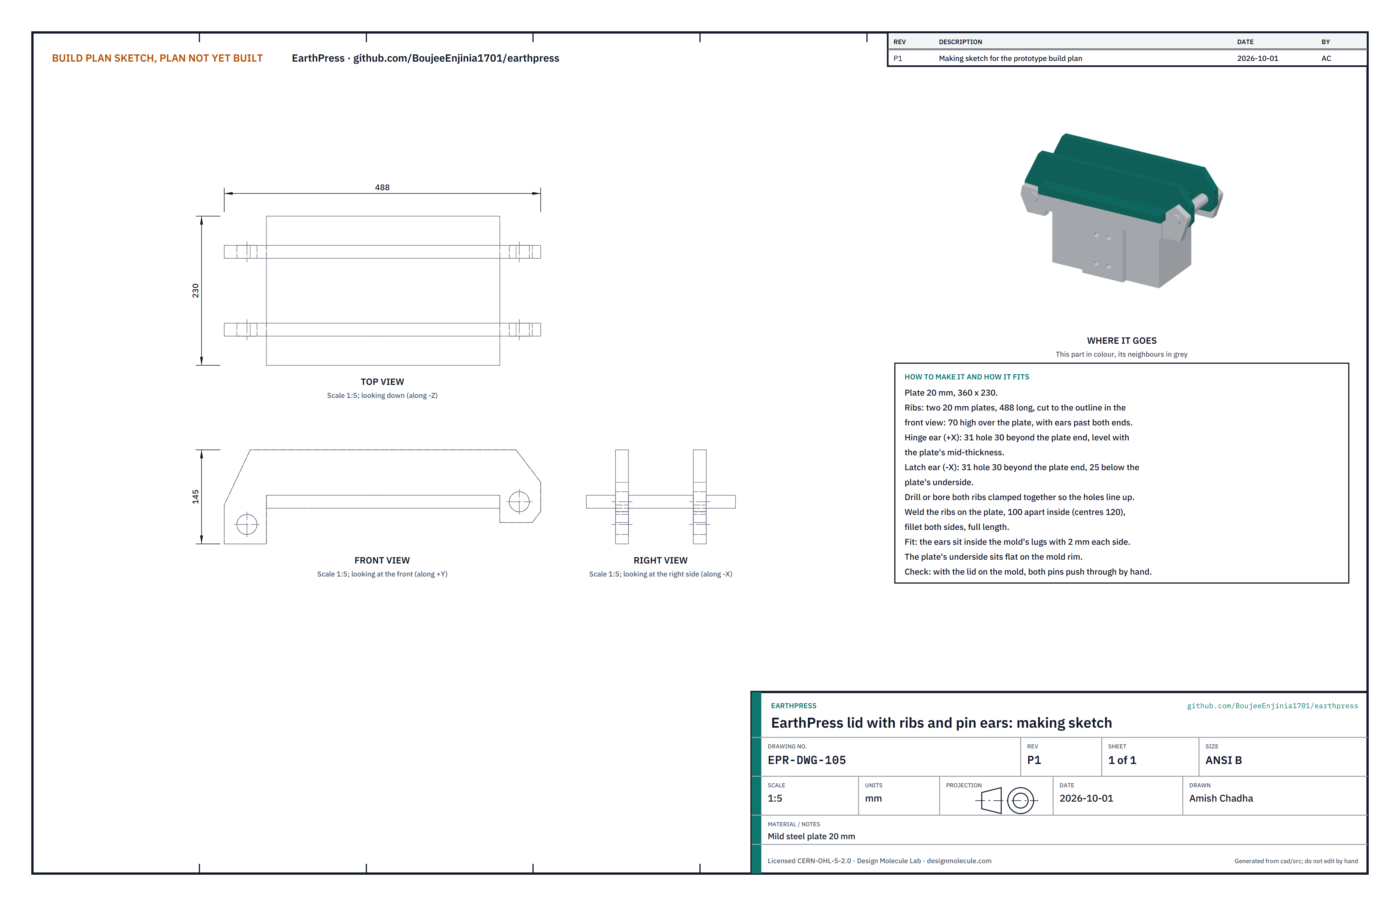
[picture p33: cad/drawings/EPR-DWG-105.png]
Figure 22. Making sketch of the lid


*Figure 22. Lid making sketch (EPR-DWG-105).*

**What it is and what it is made from.** The ribbed lid that closes the mold: its two ribs run past the plate at both ends as ears for the hinge pin and the latch pin. One welded piece of about 25 kg. Plate 20 mm.

**How to make it.**

1. Cut the plate, 20 mm, 360 x 230.
2. Cut the two ribs from 20 mm plate, 488 long, to the outline of Figure 22. Clamp them together and drill both 31 holes through both.
3. Weld the ribs on the plate's top face, 100 apart inside, with a fillet both sides full length, and a 30 bar through each pair of holes so they stay in line.

**How it fits the parts next to it.**

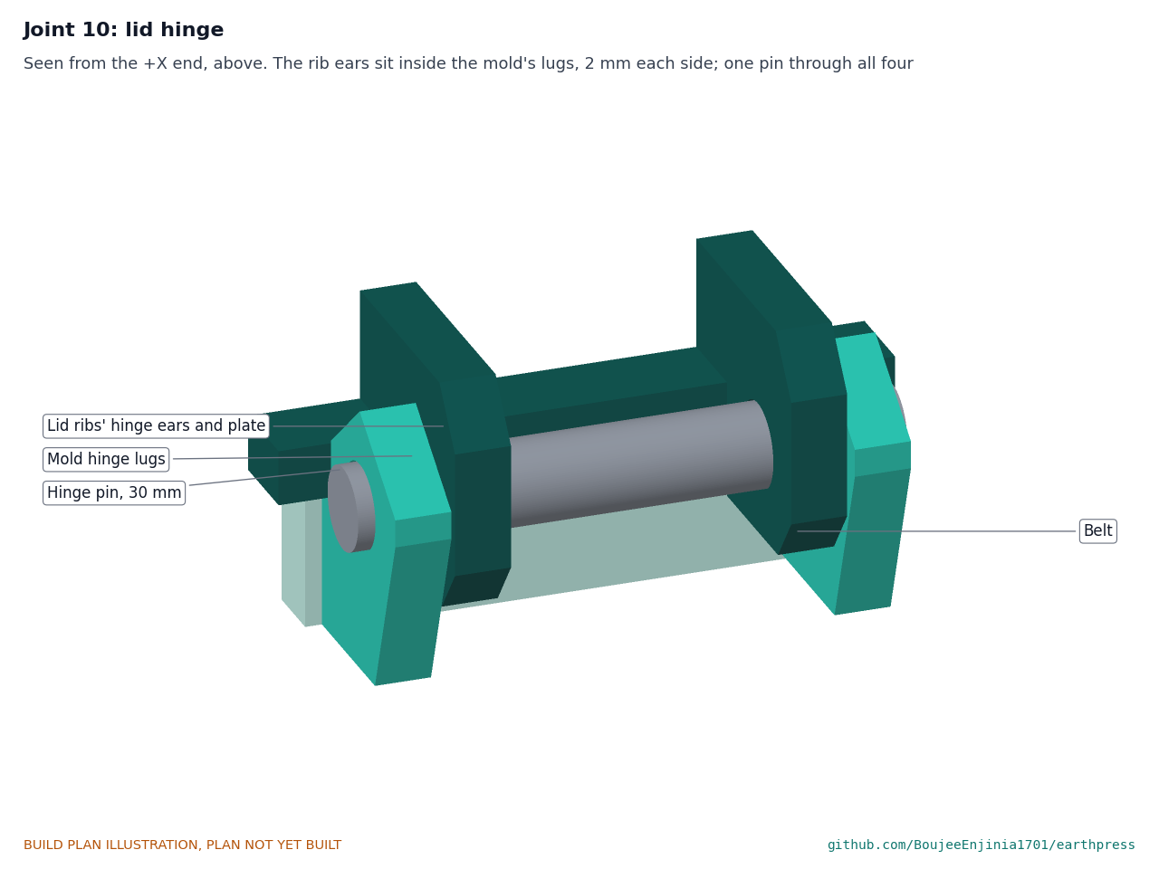
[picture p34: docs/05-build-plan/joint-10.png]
Figure 23. Joint 10: the lid hinge


*Figure 23. Joint 10: the ears sit inside the mold's hinge lugs, 2 mm each side, on one 30 pin with circlips.*

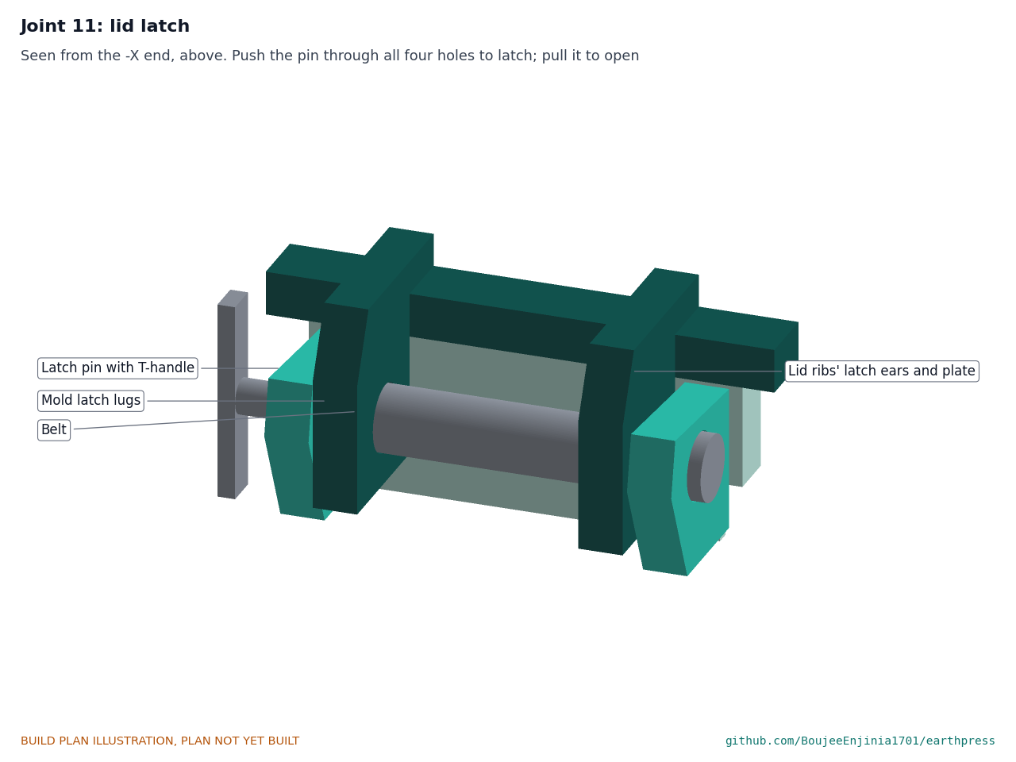
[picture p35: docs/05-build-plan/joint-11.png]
Figure 24. Joint 11: the lid latch


*Figure 24. Joint 11: to latch, push the 30 pin through the two lugs and the two ears; pull it out by its T-handle to open.*

**Check before moving on.** On the mold, the lid's underside sits flat on the rim and both pins push through by hand.

### 3.12 Lever pipe and T-handle

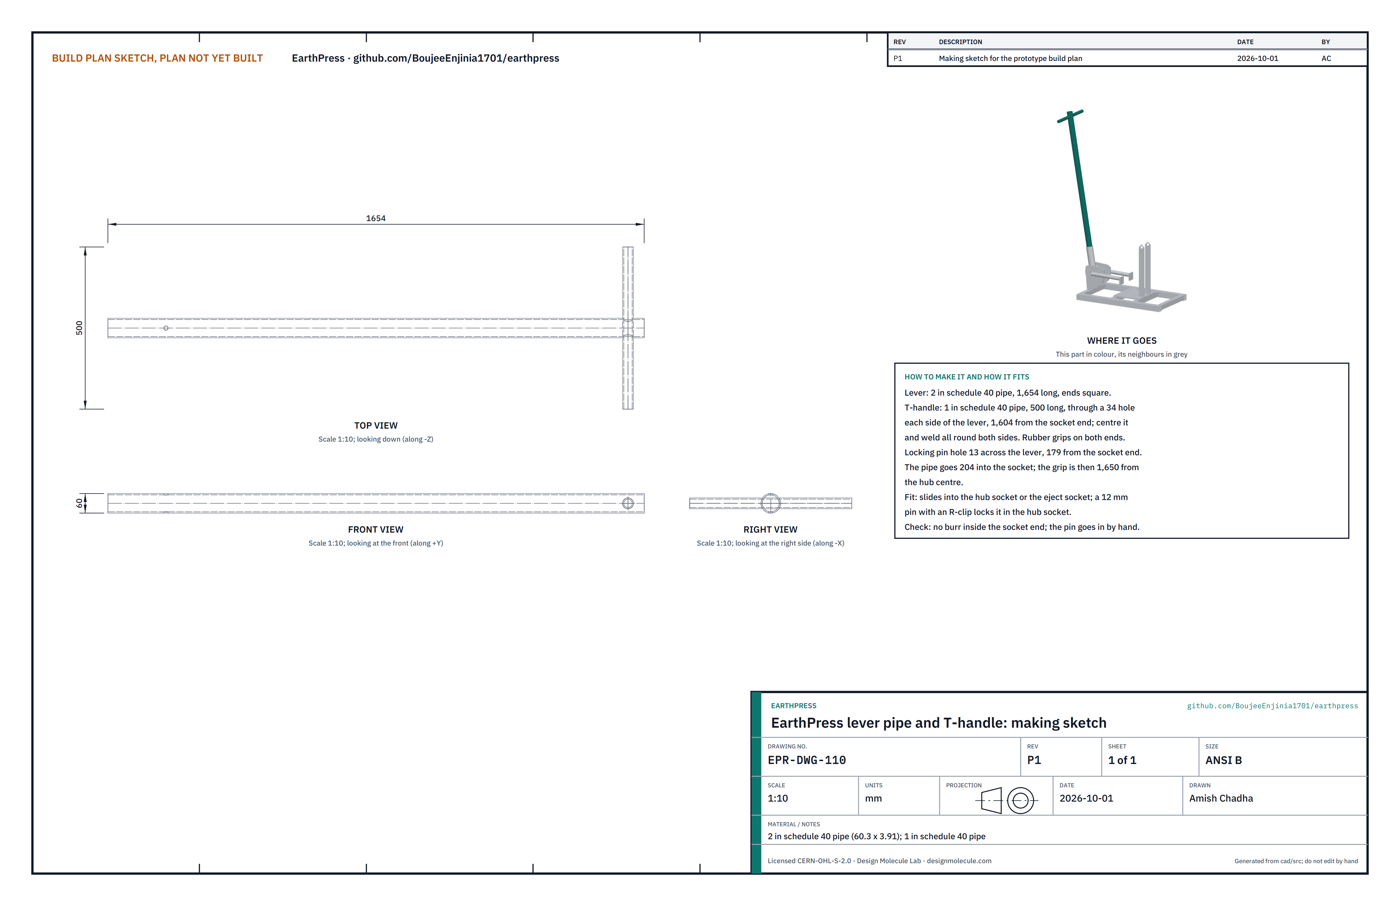
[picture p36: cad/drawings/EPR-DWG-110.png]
Figure 25. Making sketch of the lever pipe


*Figure 25. Lever pipe making sketch (EPR-DWG-110).*

**What it is and what it is made from.** The removable lever with a T-handle so two people can pull together. 2 in schedule 40 pipe (60.3 x 3.91) and 1 in schedule 40 pipe.

**How to make it.**

1. Cut the lever 1,654 long, ends square and deburred inside.
2. Drill a 34 hole through both walls 1,604 from the socket end; pass a 500 length of 1 in pipe through, centre it and weld all round on both sides. Fit rubber grips on its ends.
3. Drill a 13 hole across the lever, 179 from the socket end, for the locking pin.

**How it fits the parts next to it.** The pipe goes 204 into the hub socket, where a 12 mm pin and R-clip lock it; the grip is then 1,650 from the hub centre. It also fits the eject socket.

**Check before moving on.** The pipe slides into both sockets; the locking pin goes in by hand.

### 3.13 Block gauge

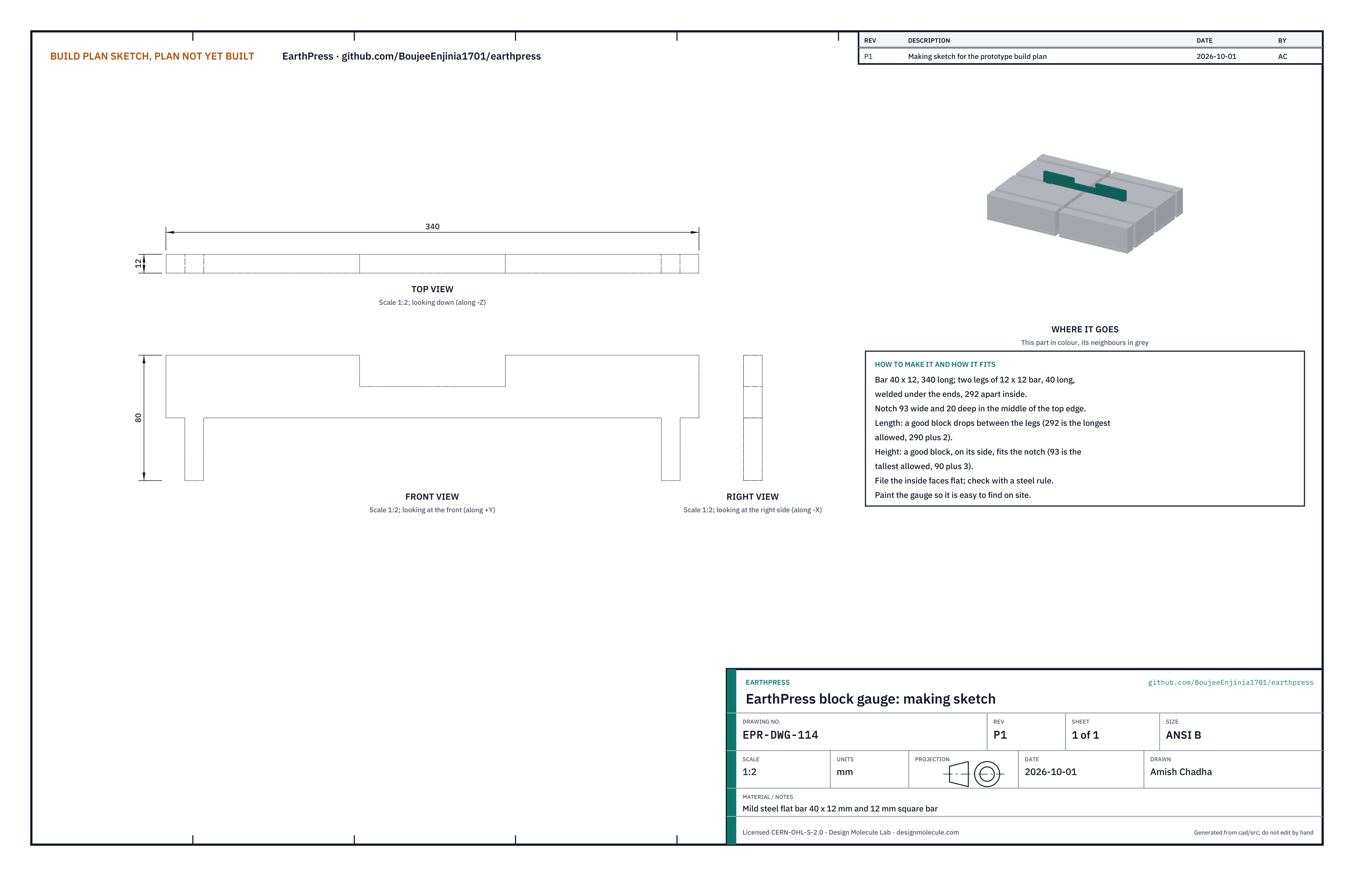
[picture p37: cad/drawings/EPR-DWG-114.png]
Figure 26. Making sketch of the block gauge


*Figure 26. Block gauge making sketch (EPR-DWG-114).*

**What it is and what it is made from.** A bar that checks every block for length and height. Flat bar 40 x 12 and 12 mm square bar.

**How to make it.** Cut the bar 340 long and two legs of 12 square bar 40 long; weld the legs under the ends, 292 apart inside. Cut a notch 93 wide and 20 deep in the middle of the top edge. File the inside faces flat and paint it.

**How it fits.** A good block drops between the legs (292, the longest allowed) and, on its side, into the notch (93, the tallest allowed).

**Check before moving on.** Measure 292 and 93 with a steel rule.

### 3.14 Soil sieve

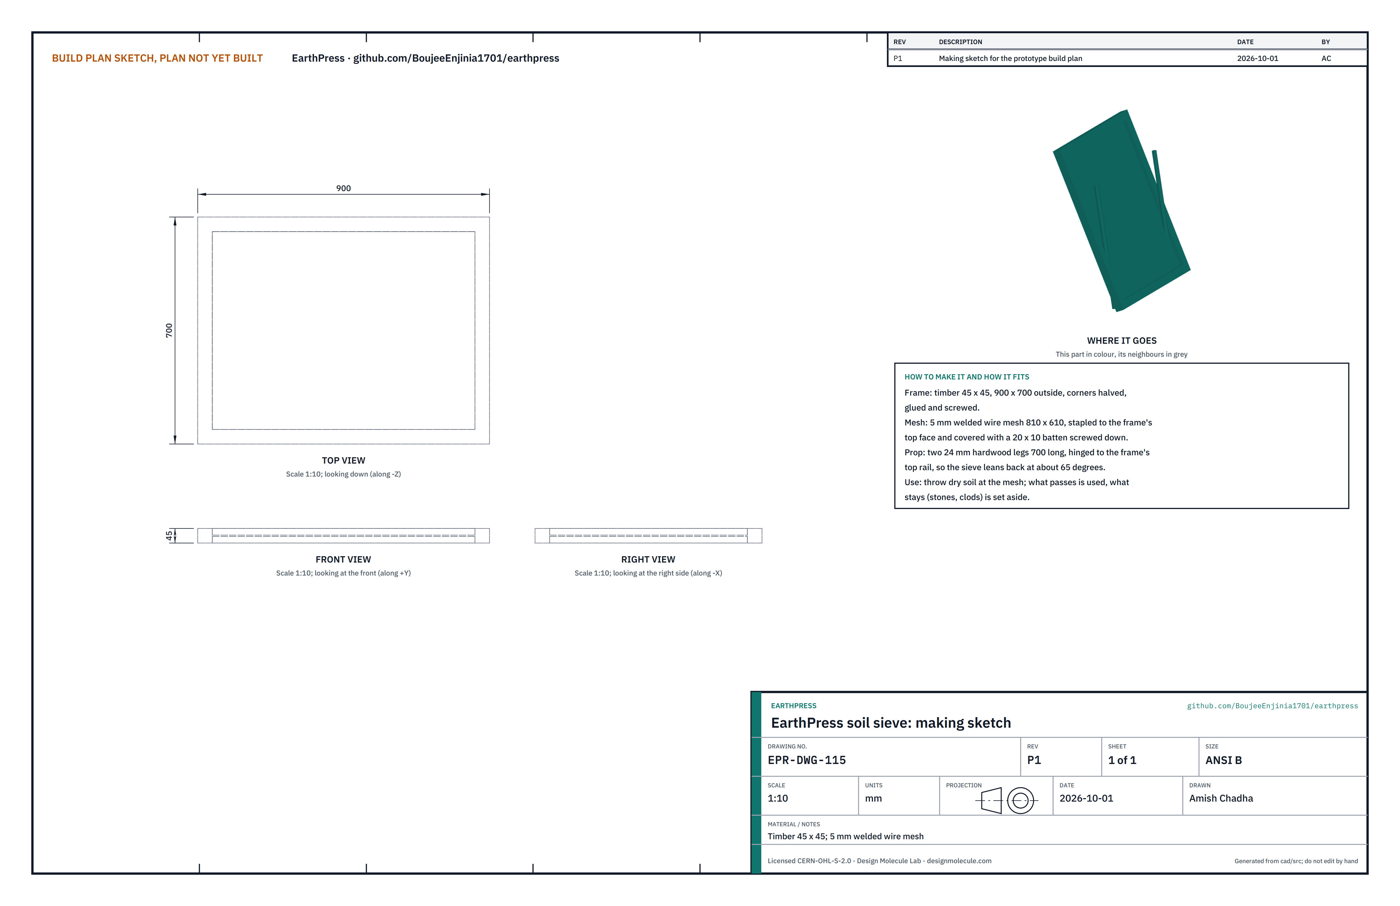
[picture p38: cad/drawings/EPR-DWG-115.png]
Figure 27. Making sketch of the soil sieve


*Figure 27. Soil sieve making sketch (EPR-DWG-115).*

**What it is and what it is made from.** A screen that takes stones and clods out of the dug soil. Timber 45 x 45, 5 mm welded wire mesh, two 24 hardwood legs.

**How to make it.** Make a frame 900 x 700 outside with halved corners, glued and screwed. Staple the mesh to the top face and screw a 20 x 10 batten over its edges. Hinge two legs 700 long to the top rail so the sieve leans back at about 65°.

**Check before moving on.** The mesh is tight and has no torn wires.

### 3.15 Soil test kit: how to use it, with the operating chart and the lime chart

The kit (BOM line 9) tells you whether a soil can be used and how to fill the mold. The numbers below are calculated, not yet tested; the laminated chart in the kit repeats them, and they are redone for each soil once a partner's soils are measured.

**Choosing and mixing.** Sieve the soil through the 5 mm mesh. Run the jar test and the shrinkage box test as printed on the chart to see whether the soil is sandy, silty or clay-rich. Cement at 5 % of the dry soil mass is the default; lime is the option for clay-rich soils or where cement is scarce.

**Weighing every fill.** Weigh each fill of moist mix on the hanging scale: 7.64 kg is the nominal mass for the 290 x 140 x 90 mm block.

*Table 2. Operating chart for the design soil (the softer soil), two operators on the T-handle.*

| Fill over the nominal 7.64 kg | Result at the stop | Peak pull for each operator | What to do |
| --- | --- | --- | --- |
| Under 0 % (less than 7.64 kg) | Block under strength, under 2 MPa | Under 405 N | Add soil and weigh again |
| 0 % to +2 % (7.64 to 7.79 kg) | Good block, 90 mm high | 405 to 498 N | Press. The target is +1 % (7.72 kg), give or take 75 g |
| Over +2 % (more than 7.79 kg) | Operators stall short of the stop; block too tall and weak | Above 500 N | Take some soil out and weigh again |

The softest soil measured so far sets this chart: the pull peaks at 809 N in total, 405 N for each operator, which is under the 500 N limit. A stiffer soil needs less pull and gives a wider fill range, so the chart is safe for it; a still softer soil needs a new chart.

**The scoop rule.** A scoop may replace weighing only for a soil where its scatter has been measured. Weigh 20 scoops of the prepared mix. Accept the scoop only if the mass of one scoop varies by no more than 34 g either way as a typical spread (a standard deviation of 34 g or less) and the average is on the target of the chart. Test again for a new soil, a new moisture or a new scoop.

**Lime option, mix chart.** These are starting values from the calculation and common practice; they are to be confirmed by block strength tests before anyone relies on them.

*Table 3. Lime mix per block and per 100 blocks.*

| Item | Cement (default) | Lime (option) |
| --- | --- | --- |
| Share of the dry soil mass | 5 % | 8 % |
| Binder per block | 0.33 kg | 0.51 kg |
| Binder per 100 blocks | 33 kg | 51 kg |
| Water per block | 0.69 kg | 0.69 kg |
| Fill mass per block | 7.64 kg | 7.64 kg |
| Keep damp under cover | About 4 weeks | About 8 weeks |

Mix the lime dry into the sieved soil first, then add the water, and press the mix the same day. The press, its stroke and the dwell are the same for both binders. Blocks made with lime gain strength more slowly, so keep them damp under cover for the longer time before stacking them for use, and handle them gently for the first two weeks. Wear gloves and eye protection when mixing lime and cement.

### 3.16 Bought components

Buy to specification, not brand. Line numbers are those of the bill of materials.

- **Toggle pins (line 5).** Three C45 turned pins, 35 diameter, with a circlip groove near each end: two 192 long (base and knee) and one 128 long (upper).
- **Bushes and spacers (line 5).** Ten case-hardened steel bushes, 35 bore, 41 outside, 28 long (eight for the links, two for the lugs); two spacer tubes 50 x 35.5 inside, 16 long (base pin) and two 20 long (knee pin); six grease nipples; eight dust seal washers of felt or rubber, 2 thick, 50 outside and 35.5 bore.
- **Hub shaft and pins (lines 3, 6, 7).** One 40 shaft 154 long; one 30 crank pin 112 long; two 30 pins 196 long (hinge and latch, the latch pin with a welded T-handle); one 30 eject pin 152 long; all C45 with circlip grooves; one 12 locking pin with R-clip.
- **Springs (line 7).** Two small torsion springs for the catch and the pawl.
- **Fixings (line 11).** Eight M16 x 20 grade 8.8 hex bolts with washers; eight M12 x 40 and four M12 x 50 grade 8.8 bolts with nuts and washers; four M10 x 30 and four M10 x 50 bolts with nuts, and four 35 mm spacer tubes; ten 10 mm washers for the hub and seesaw; circlips for every pin.
- **Soil test kit (line 9).** Two 1 L clear jars with lids, a 600 x 40 x 40 shrinkage box, three measuring buckets, a 10 kg hanging scale with 50 g divisions, salt and the laminated test chart.
- **Finish (line 11).** Primer and paint for all steel except the mold cavity, the pins and the bushes.

## 4. Putting it together

In each picture the parts already fitted are grey and the part being fitted is in colour, with an arrow showing the way it goes in. Grease every pin and bush as it goes in.

### Step 1: set the base frame level

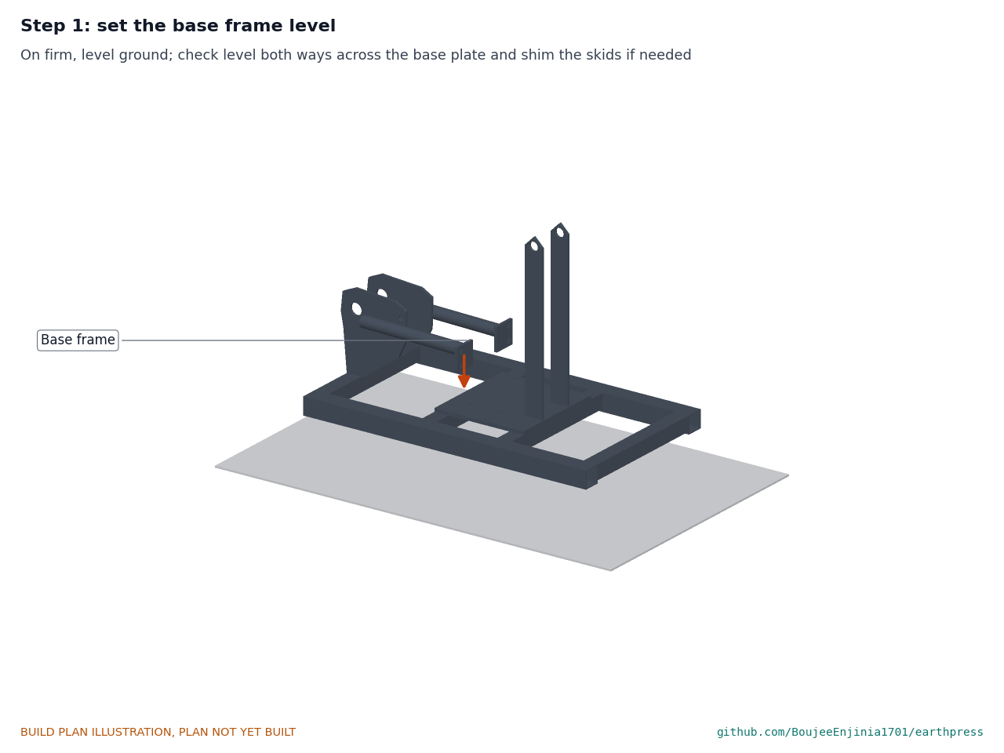
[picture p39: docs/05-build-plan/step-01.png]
Step 1


On firm, level ground. Check level both ways across the base plate and shim under the skids if needed.

### Step 2: press core onto the base plate

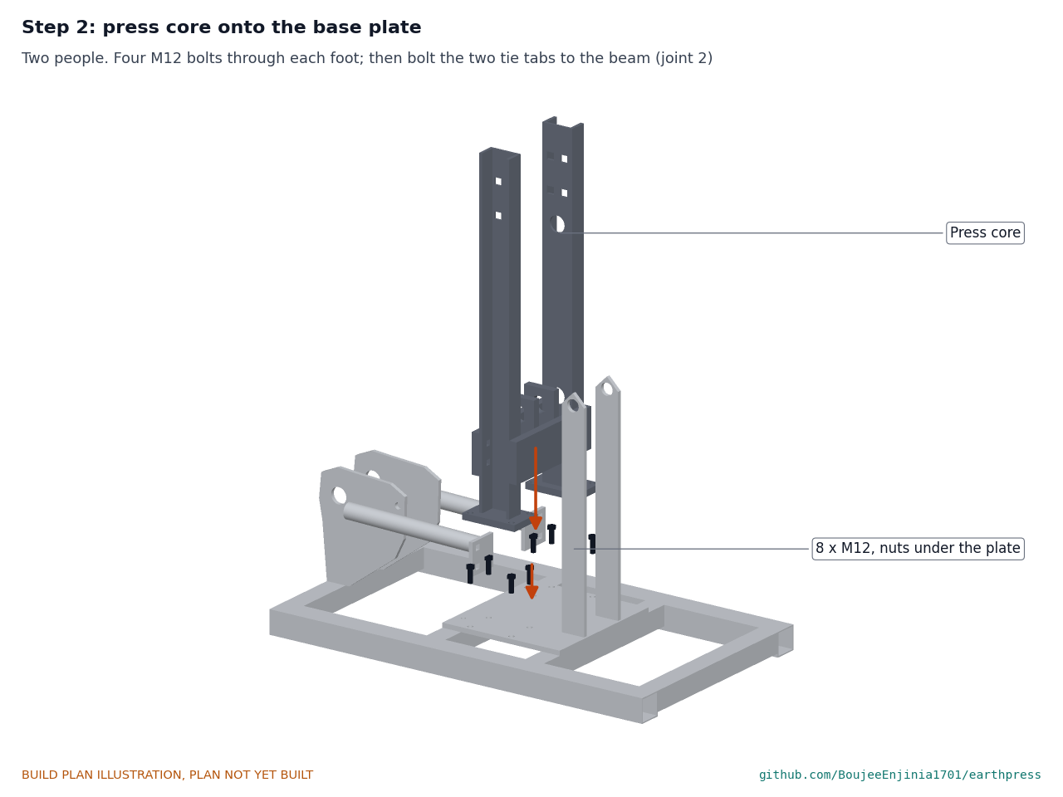
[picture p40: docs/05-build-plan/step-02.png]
Step 2


Two people lift the core (28 kg) onto the base plate. Four M12 bolts through each foot, nuts under the plate, tight. Bolt the two tie tabs to the beam with two M12 each (Figure 6).

### Step 3: mold box between the columns

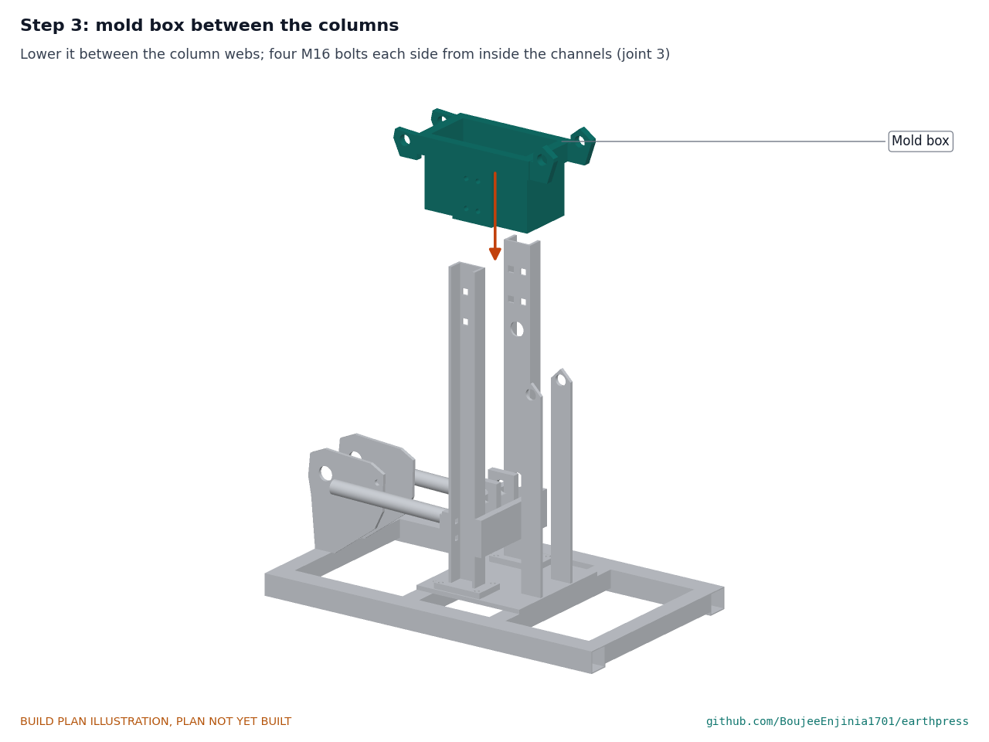
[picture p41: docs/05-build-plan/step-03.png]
Step 3


Two people lower the mold (30 kg) between the column webs from above until the bolt holes line up; a helper holds it while the first bolts go in. Four M16 bolts each side from inside the channels, tight. **Hold point:** the rim is level both ways.

### Step 4: piston into the mold from the top

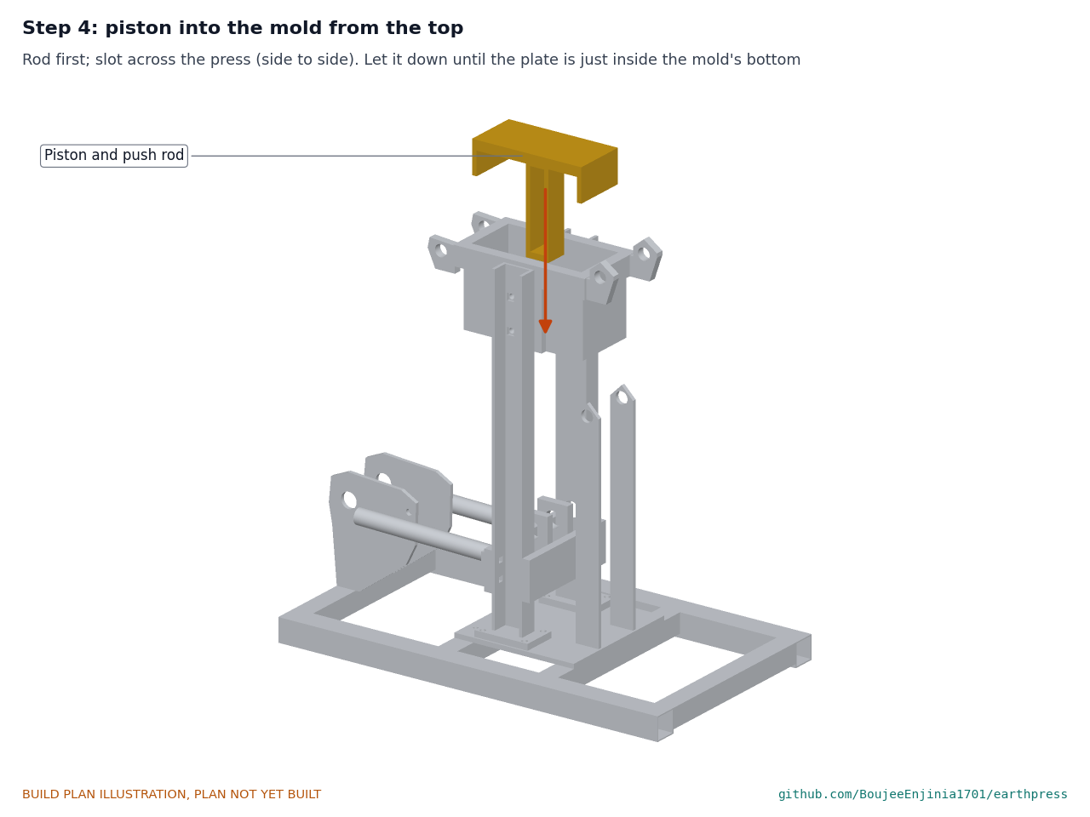
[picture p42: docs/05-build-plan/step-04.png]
Step 4


Rod first, with the slot running across the press. Let it down until the plate is just inside the mold's lower edge and hold it there with a wooden prop under the rod.

### Step 5: lower links on the base pin

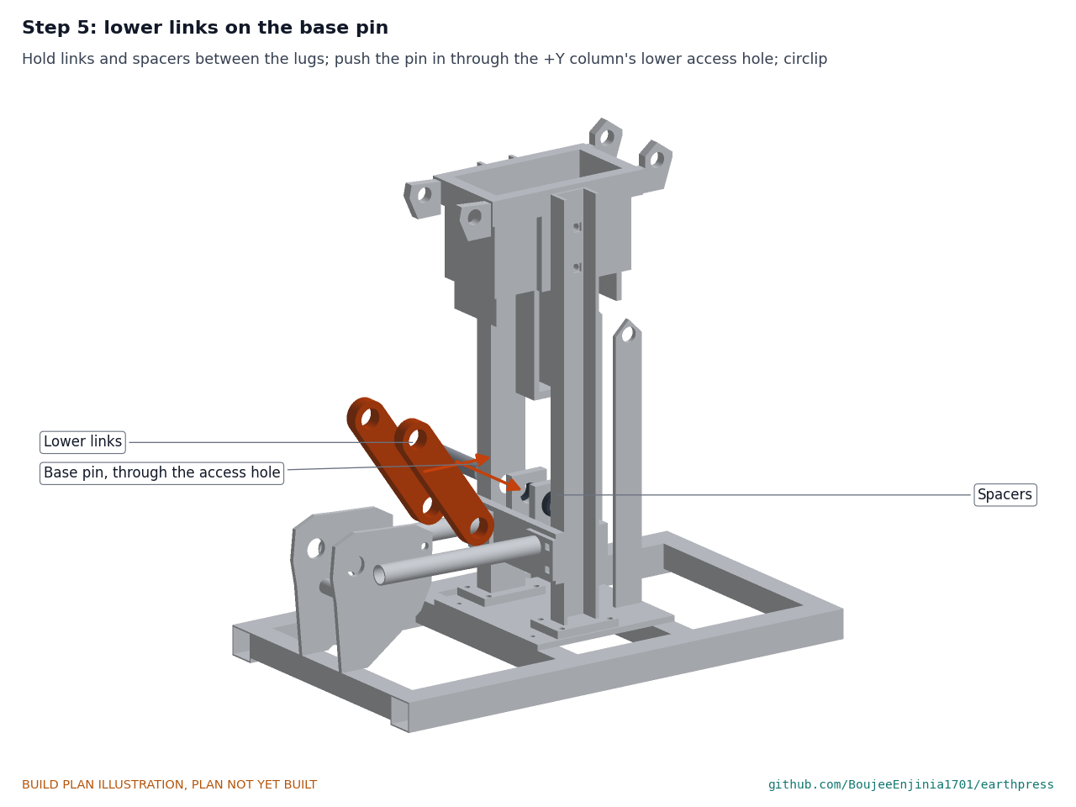
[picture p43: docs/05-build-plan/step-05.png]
Step 5


Hold the two lower links and two spacers between the lugs and push the base pin in from the +Y side through the column's lower access hole. Fit a dust seal washer on the pin against each outer link face. Circlips on both ends.

### Step 6: the knee

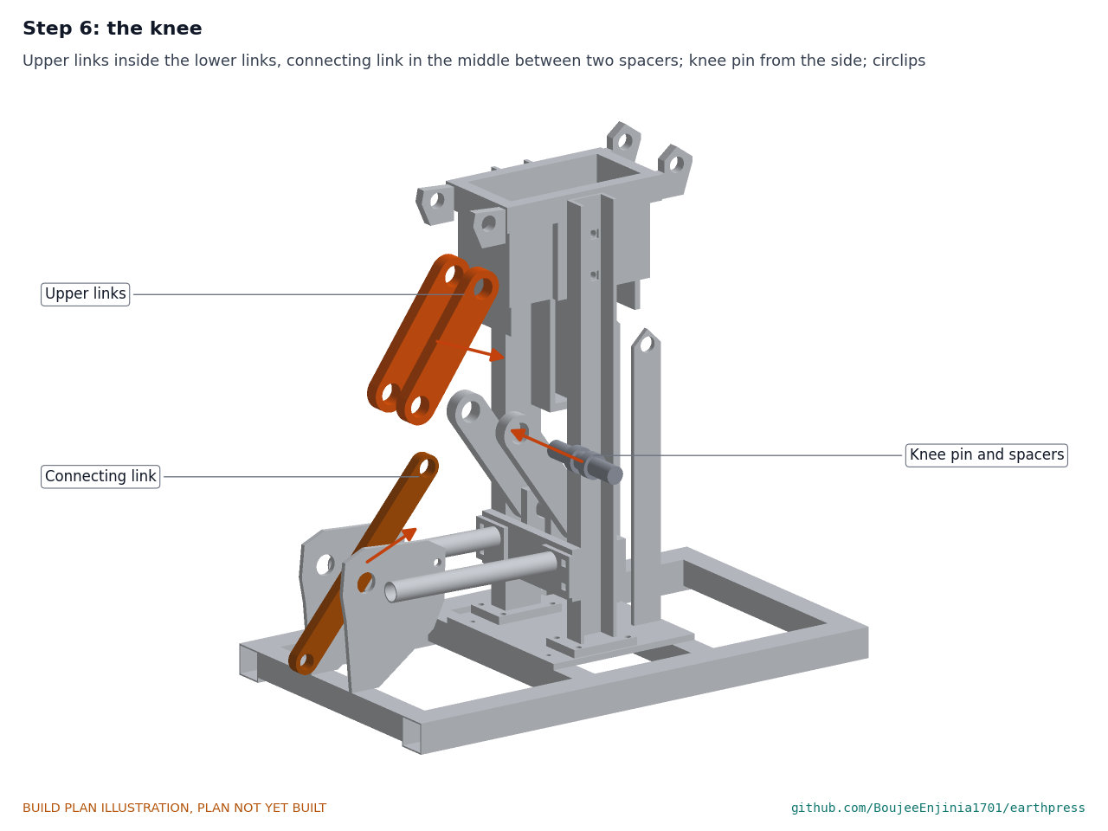
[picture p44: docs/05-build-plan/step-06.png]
Step 6


Put the upper links inside the lower links' free ends, the connecting link in the middle between the two knee spacers, and push the knee pin through from the side. Fit a dust seal washer against each outer link face before the circlips. Circlips.

### Step 7: upper pin through the rod's slot

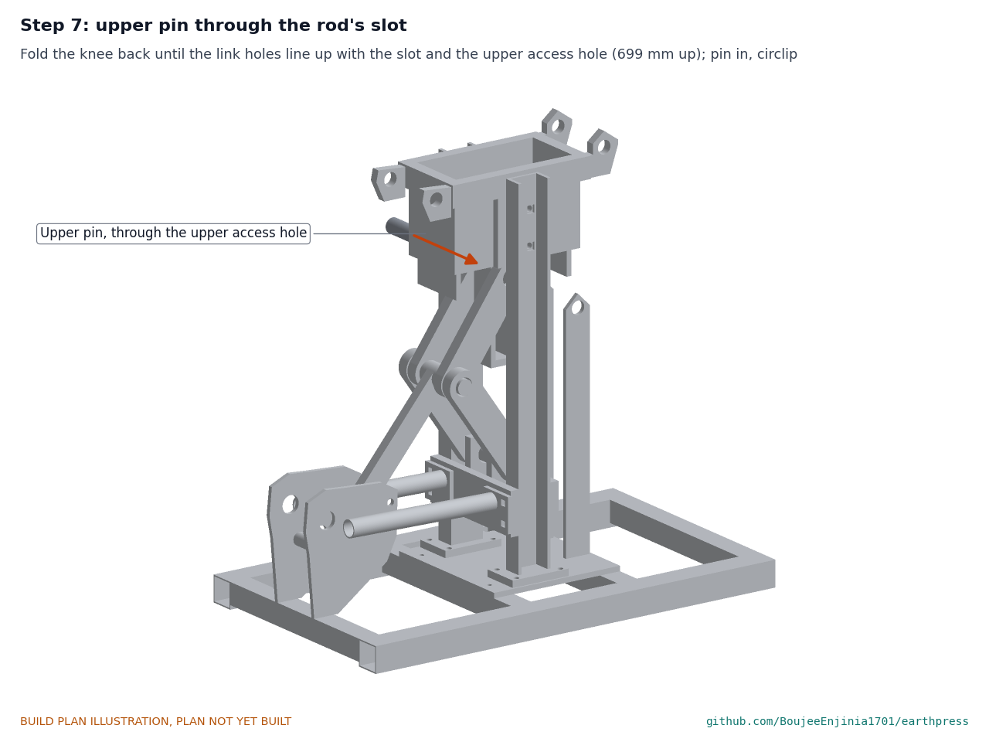
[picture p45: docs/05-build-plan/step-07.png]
Step 7


Fold the knee back until the upper links' holes line up with the rod's slot and the column's upper access hole (699 above the ground); move the piston's prop to suit. Push the upper pin in through the access hole, the links and the slot. Fit a dust seal washer against each outer upper link face. Circlips. Take out the prop.

### Step 8: lever hub on its shaft; crank pin

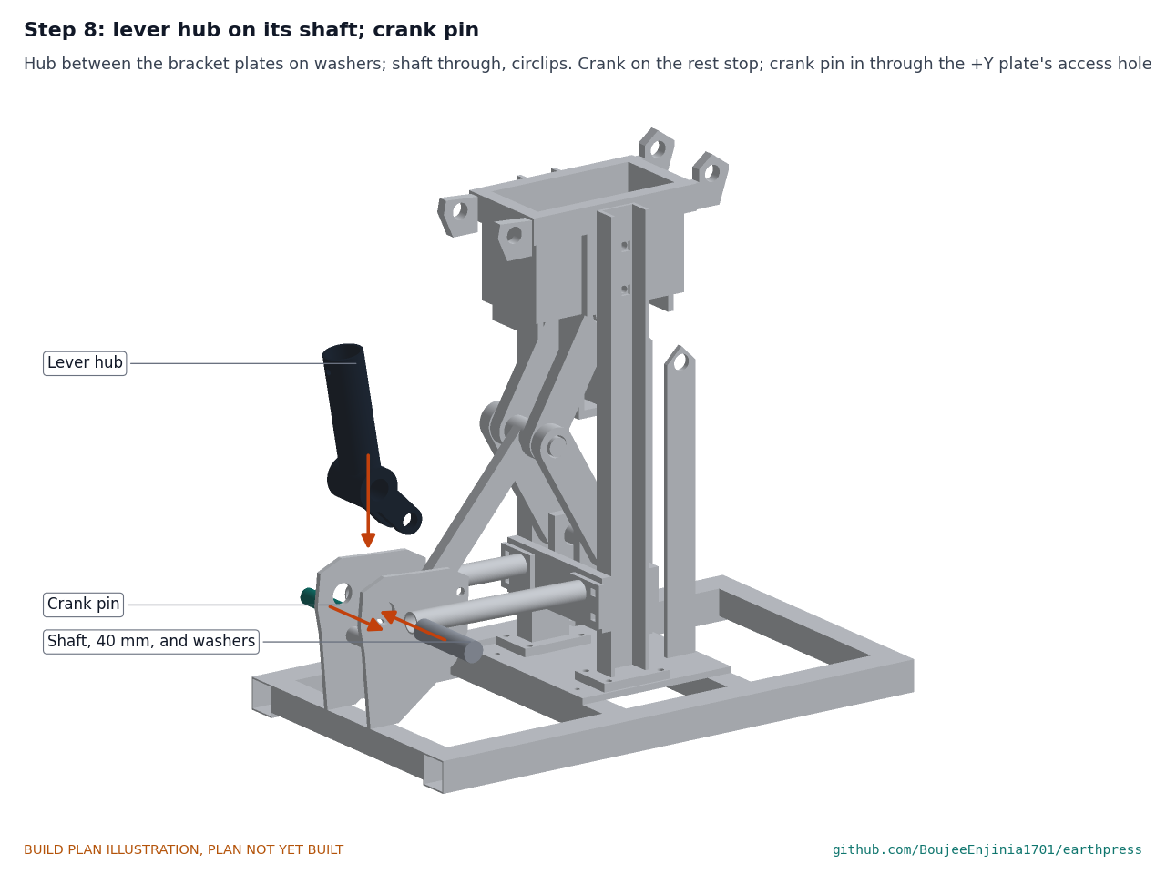
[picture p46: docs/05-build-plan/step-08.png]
Step 8


Seen from behind. Hold the hub between the bracket plates with a 10 mm washer each side and push the shaft through; circlips. Swing the crank to the connecting link's free end, with the crank plates on the rest stop, and push the crank pin in through the access hole in the +Y bracket plate, the crank plates and the link. Circlips.

### Step 9: rest catch and end pawl

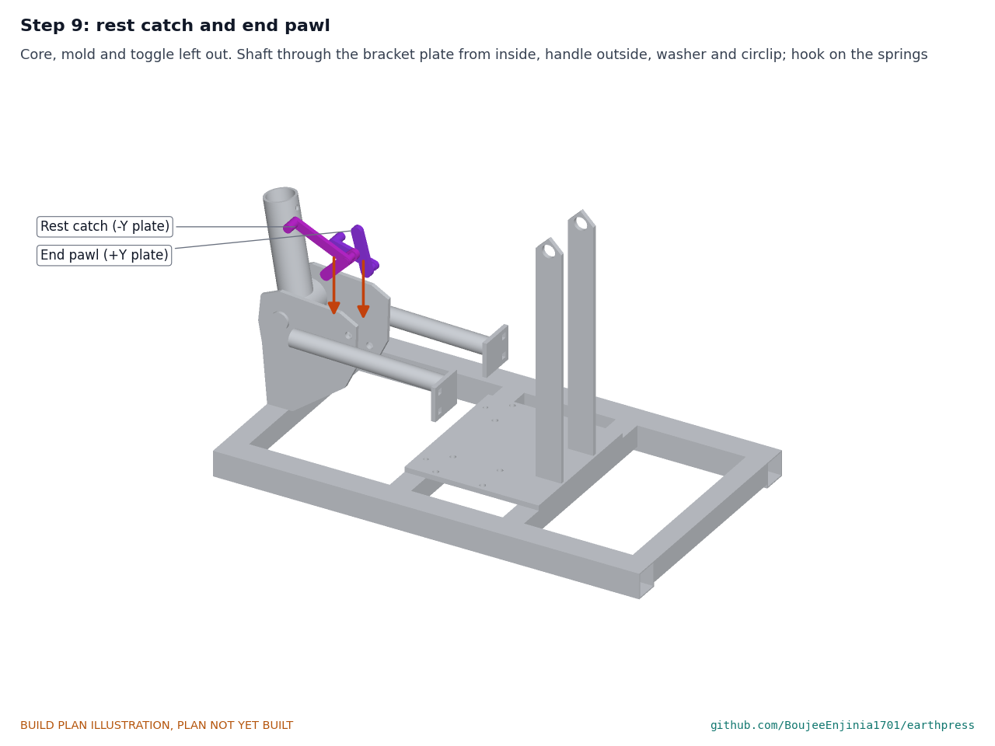
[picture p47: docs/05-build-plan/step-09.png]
Step 9


Fit each shaft through its bracket plate from the inside, with a washer; weld or bolt on the handle outside; circlip; hook on the spring. The catch goes on the -Y plate, the pawl on the +Y plate.

### Step 10: eject seesaw between the posts

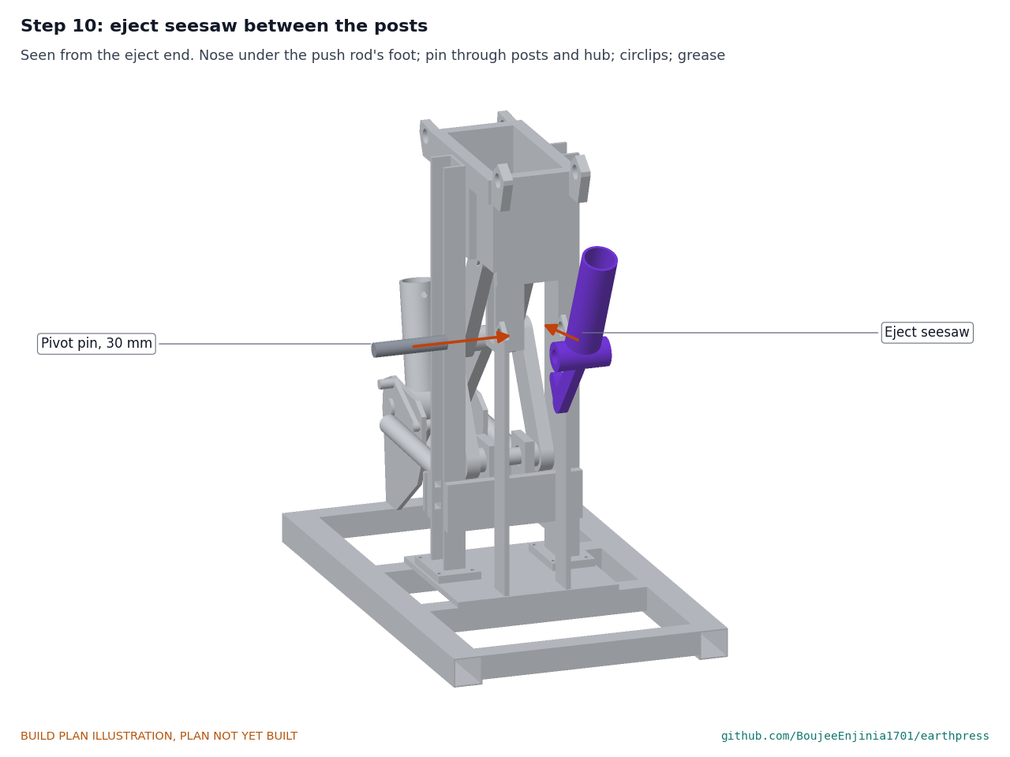
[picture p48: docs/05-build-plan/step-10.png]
Step 10


Hold the seesaw between the posts with a washer each side, nose under the push rod's foot, and push the pivot pin through. Circlips.

### Step 11: linkage guard

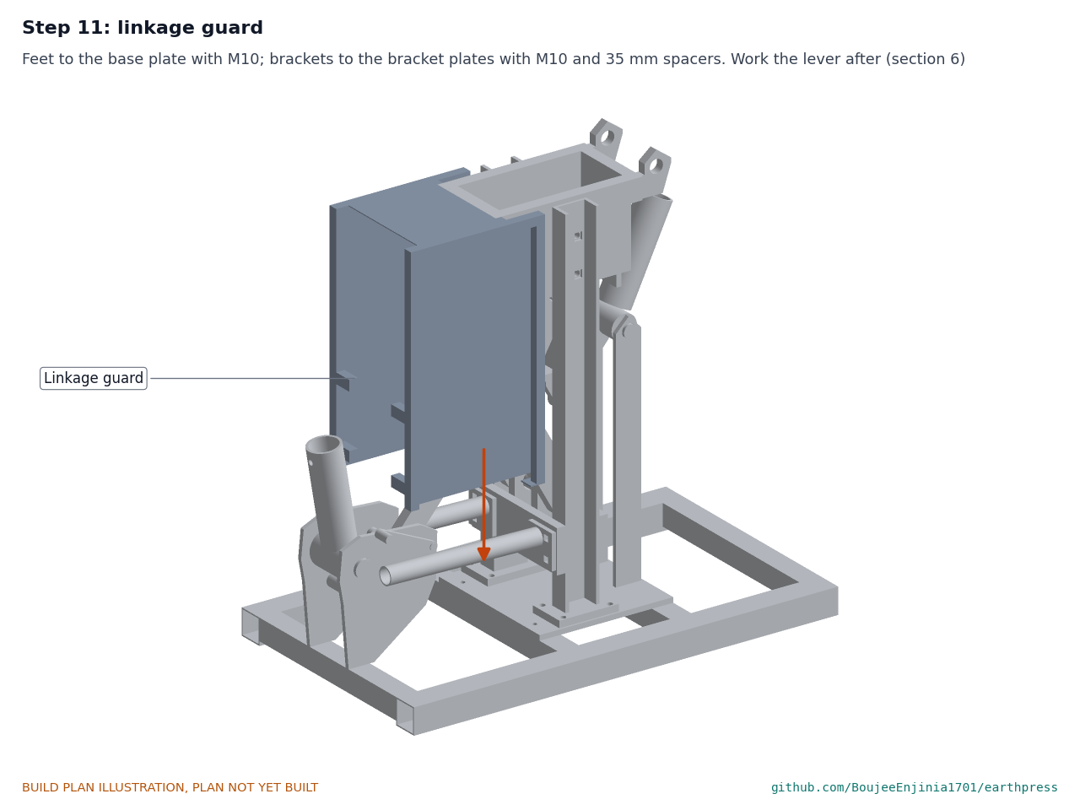
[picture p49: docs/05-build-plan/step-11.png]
Step 11


Seen from behind. Feet to the base plate with M10 bolts; brackets to the bracket plates with M10 bolts through the 35 mm spacers. **Hold point:** safety stop S2 in section 6.

### Step 12: lid, hinge pin and latch pin

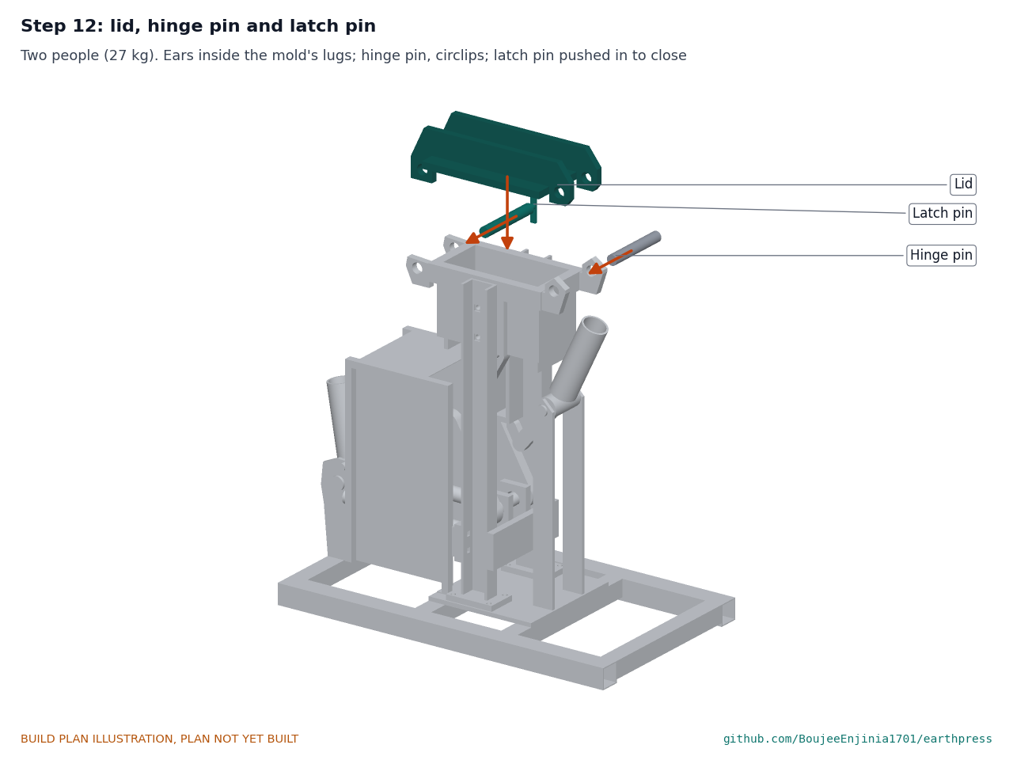
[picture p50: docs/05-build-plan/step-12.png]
Step 12


Two people lift the lid (27 kg) onto the mold with its ears inside the mold's lugs. Hinge pin through, circlips. Close the lid and push the latch pin through.

### Step 13: lever into the hub socket

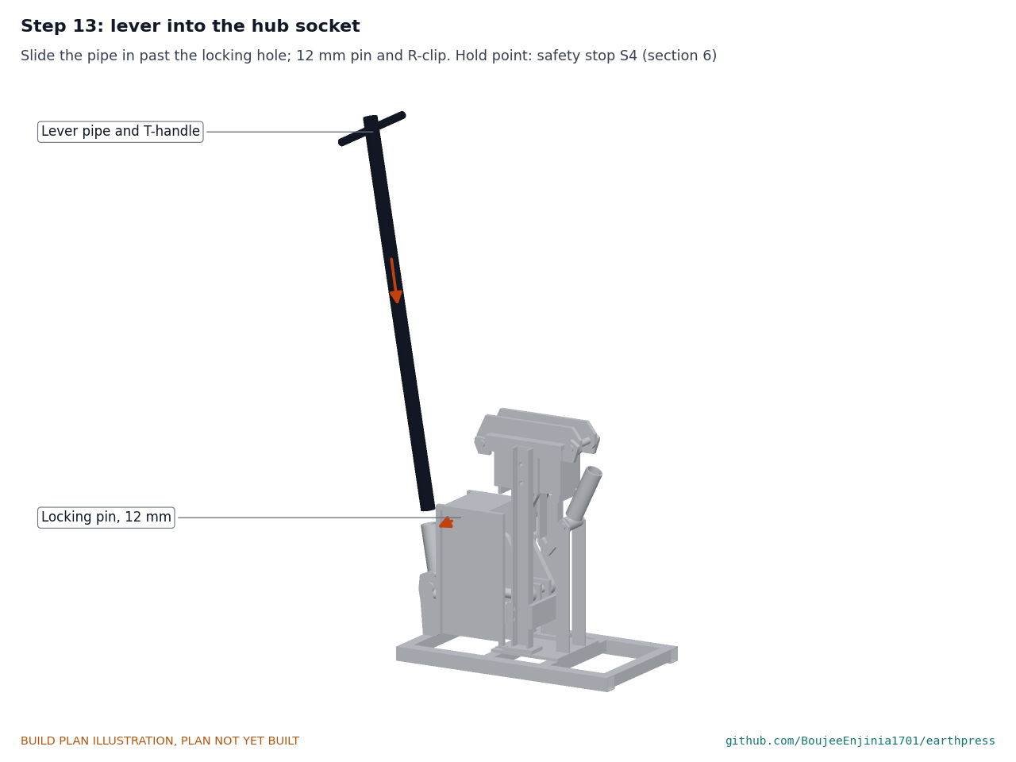
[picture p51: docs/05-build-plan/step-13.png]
Step 13


Slide the pipe into the hub socket past the locking hole; fit the 12 mm pin and R-clip. **Hold point:** safety stop S4 in section 6.

## 5. First checks

These are the checks a TRL 4 test report would record; this plan only lists them. Requirement numbers are those of EPR-REQ-001.

*Table 4. First checks.*

| Check | Requirement | How | Pass when |
| --- | --- | --- | --- |
| Cavity size | R1 | Measure the cavity at top and bottom | 290 x 140 within 1 mm, square |
| Free stroke, mold empty | R2, R12 | Lid open, lift the catch, take the lever slowly through the full stroke and back | Nothing binds or touches; the pawl drops in at the end and the catch at the start; the piston rises 60 mm |
| Clearances | R12 | Watch the crank, connecting link, knee and eject arm through the stroke | Nothing touches the guard, the ties or the frame |
| Lid and latch | R12 | Close the lid; push the latch pin in and out | Pin goes in by hand; the lid sits flat on the rim |
| Ejection, mold empty | R5 | Lever in the eject socket; pull down | The piston face rises to 10 mm above the rim; pull under 100 N with no block |
| Grip heights | R5 | Measure the T-handle at the start and the end of the stroke | About 1.89 m and 0.86 m above the ground |
| First block | R1, R2 | Weigh the fill to the chart's target, press with two people to the stop, eject | Block comes out whole; height 90 within 3 mm on the gauge |
| Pull force | R5 | Spring balance on the T-handle on a test block | 1,000 N or less in total at the peak; record it |
| Kickback | R12 | At the end of a press, let go with the pawl engaged | The lever stays at the end; the pawl takes the load |
| Mass of each piece | R7 | Weigh each piece on a platform scale | 50 kg or less each; record the total |
| Cycle time | R4 | Time ten blocks with a crew of four | Record it; 85 s or less is the target |

## 6. Safety stops

Stop at each point. Carry on only when everything listed is true.

- **S1. Before any welding or cutting.** Welding helmet, gloves, leather apron and safety glasses on; fire extinguisher within reach; nothing that burns within 10 m; the grinder has its guard.
- **S2. Before the lever is fitted.** Every bolt is tight; every pin has a circlip at each end; the guard is in place; nothing moves by hand except the toggle, hub, catch, pawl and seesaw.
- **S3. Before anyone lifts a piece.** Two people for every piece over 25 kg (base frame, core, mold, lid); gloves and safety boots.
- **S4. Before the first stroke.** The lid is either open with the mold empty, or closed and latched; two people on the T-handle; everyone else 2 m clear; no hands near the mold, the linkage or the eject arm; the catch and the pawl work (section 5).
- **S5. Before the first block.** Gloves, long sleeves, eye protection and an FFP2 or N95 respirator for mixing cement and sieving soil; sieve damp soil where possible.
- **S6. At every stroke.** Engage the pawl before letting go at the end; hold the lever while lifting the pawl and walk it back to rest; never open the latch until the lever is back on its rest stop with the catch in.

## 7. Tools, skills and workspace

**Tools.** Stick welder (about 160 A) with rods for mild steel; angle grinder with cutting, grinding and flap discs; plasma or oxy-fuel cutter for the shaped plates (or a band saw and patience); drill press with drills to 18 and a 40 or 41 bore (or a holesaw and a boring bar, or bought bored parts); M16 tap and tap wrench; set of files; clamps and a flat welding table about 1.2 x 0.6 m; square, rule, calipers and a 1 m straightedge; spirit level; socket set to 24 mm; circlip pliers; vice or small press for the bushes; a 35 reamer; spring balance to 100 kg; platform scale to 50 kg; stopwatch.

**Skills.** A competent welder for structural fillet welds in 10 to 20 mm plate; basic machine-shop work (drilling, tapping, pressing in bushes). The turned pins, shaft and bushes are bought from a machine or bearing shop. No electrical work is part of this build.

**Workspace.** A workshop floor at least 3 x 3 m; a flat table for tacking the frames square; a clear 2 m zone round the press for the first strokes.

**Personal protective equipment.** Welding helmet, gloves and apron; safety glasses and hearing protection for grinding; safety boots; for using the press, gloves, eye protection and a respirator for cement and dry soil.

## 8. Where the numbers come from

- Model and constructability checks: `cad/src/model.py` (`python cad/src/model.py --check`); STEP and STL exports in `cad/step/` and `cad/stl/`.
- Pictures: `cad/src/build_plan_media.py`, using `.kit/build_views.py`; written to `docs/05-build-plan/` and `cad/drawings/EPR-DWG-101` to `EPR-DWG-115`.
- General arrangement: `cad/drawings/EPR-DWG-001.pdf`, Rev P3.
- Calculations: `docs/04-calcs/01-sizing.md` (EPR-CAL-001 v0.6) and `docs/04-calcs/sizing.py`; forces and grip heights section 4, structure section 6, ejection section 7, mass section 8; operating chart section 4b and lime chart section 4c of `sizing.py`.
- Bill of materials: `bom/bom.csv`.
- Decisions: `docs/decisions/0003-design-for-construction.md` (EPR-DDR-003), with EPR-DDR-001 and EPR-DDR-002; `docs/06-design-decisions.md` (EPR-DEC-001).
- Requirements: `docs/03-requirements.md` (EPR-REQ-001 v0.8).

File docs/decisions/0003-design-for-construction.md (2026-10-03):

---
doc_id: EPR-DDR-003
title: EarthPress design for construction
project: EarthPress
doc_type: Design decision record
version: "0.4"
status: Draft
date: '2026-10-02'
author: Amish Chadha
license: CERN-OHL-S-2.0
revisions:
- version: "0.1"
  date: '2026-10-01'
  author: Amish Chadha
  change: Changes that make the concept physically buildable, with the reason for each; made under Amish's 2026-09-30 instruction to make the design physically buildable; open for his review
- version: "0.2"
  date: '2026-10-01'
  author: Amish Chadha
  change: Budget treated as a value-engineering target
- version: "0.3"
  date: '2026-10-02'
  author: Amish Chadha
  change: "A1 and A3 accepted by Amish (2026-10-02); Table 1 still open for his review; status kept Draft"
- version: "0.4"
  date: '2026-10-02'
  author: Amish Chadha
  change: "Table 1 changes (P1 to P15) accepted by Amish on 2026-10-02"
---

# 0003: Design for construction

- **Date:** 2026-10-01
- **Status:** accepted. Amish, 2026-10-02: "APPROVED: Design-for-construction changes in 10 repos (CityTwin, CoolShade, PalletPilot, Heliolite, PotholeLog, EarthPress, ReadyKit, CellCheck, CargoMule and ThermaCart)". This covers the changes P1 to P15 in Table 1, made under Amish's 2026-09-30 instruction to make the design physically buildable, and is recorded in the design decisions register (EPR-DEC-001). Of the items in Table 3, A1 and A3 were accepted by Amish earlier the same day as recommended in the design decisions register (EPR-DEC-001): "i approve your recommendations for all 555 open decisions." A2 needed no decision and is carried in the register's Value engineering section.

## Context

On 2026-09-30 Amish asked for a build plan for every repo that shows how each component is made and how it fits the next, with pictures, and wrote: "If you are realising that the design cannot be built as per concept - fix the design assumptions to match and be physically feasible as you draw the illustrations." The TRL 3 model of EPR-DDR-002 showed what EarthPress does and that it works on paper, but several of its parts floated, overlapped a moving part or had no fixing. Checking the model with build123d (part-to-part overlaps at seven poses through the stroke and the eject, contacts, clearances of every moving part, and assembly order) found the fifteen problems below.

The changes keep what the press does: the same block, mold rim height, toggle, lever pivot, lever arc, grip heights, force ratio, crank stop, eject lift and two-person operation. No requirement target, pitch, problem or safety case is changed. Every change is in `cad/src/model.py`, which now builds each part on its own (`build_components`) and runs 47 constructability checks (`python cad/src/model.py --check`); all 47 pass.

## Decision

*Table 1. Changes made to the model, the BOM and the calculations.*

| # | Problem in the concept | Change made | Why this way |
| --- | --- | --- | --- |
| P1 | The base plate floated: the cross tubes sat 5 mm below the skid tops and none of them was under the plate. | Cross tubes raised flush with the skid tops; the two inner tubes moved under the base plate's edges; base plate 315 x 340 mm (was 240 x 380 mm) so it also carries the eject posts. | The plate now sits and is welded on two tubes; the posts stand on it. |
| P2 | The UPN 80 columns faced the mold with their open side, so the eight M16 bolts had no place for a nut (the flange is welded to the mold wall). The base beam plates overlapped the column flanges, and the base pin lugs floated above the beam's bottom plate. | Columns turned so the webs face the mold; the mold flanges are drilled and tapped M16 and the bolts go in from inside the open channel. Beam plates moved to the outside faces of the column flanges and welded there; lugs welded between the beam plates; bottom plate removed. Column feet get four M12 bolts each. | Every bolt can be reached with a socket from the open side of the channel; the beam and lugs form one welded clevis. |
| P3 | The push rod guide strap under the mold sat in the path of the upper links and upper pin, which rise into the mold (to 820 mm) at the end of the stroke; the upper pin's ends also passed through the mold walls. | Guide strap removed. The piston gets two 12 mm end skirts, 60 mm deep, that keep it square in the cavity. Upper pin shortened to 128 mm so it stays inside the cavity's width. | A plate 288 mm long and 25 mm thick could tip in a 290 mm cavity; with the skirts it cannot. |
| P4 | The base pin and upper pin could not be fitted: a 192 mm pin along the press's width is blocked by the column webs. Links had up to 20 mm of free play along the pins. | 40 mm access holes in the +Y column web at the base pin and at the upper pin (fitted with the toggle folded to 35°, upper pin at 699 mm). The knee pin goes in from the side, outside the columns, and the crank pin through a 31 mm access hole in the +Y lever bracket plate with the lever at rest. Spacer tubes on the base pin (two of 16 mm) and knee pin (two of 20 mm). Pins end 2 mm inside the column webs. | Each hole takes about 22 % of the column's section; the column's net section is still 2.5 times stronger than needed at the 173 kN design load [EPR-CAL-001 section 6]. |
| P5 | The links stopped at the pin centres, with no metal round the holes. | Round ends of half the link width on all four toggle links, the connecting link, the crank plates and the eject arm. Bushes 41 mm outside diameter pressed into the links. | A link needs metal round its hole; the net section at the bush is checked [EPR-CAL-001]. |
| P6 | The lid's hinge knuckle cut into the mold belt, and the hinge base had no pin through it. | The lid's two ribs are cut long as ears; the 30 mm hinge pin passes the two ears and two 20 mm lugs on the mold belt, 210 mm from the centre line. Knuckle tube removed. | Four plates on one pin, each ear inside a lug: the pin works in double shear as the calculation assumed. |
| P7 | The latch hook sat above its keeper and could not hold the lid down. | Latch: a 30 mm pin with a T-handle, pushed through ears on the lid ribs and two lugs on the mold, 210 mm from the centre line. | A pin through lugs is the simplest latch that holds the full 173 kN. |
| P8 | The rest stop bar sat in the path of the lever socket and would stop the stroke; the end pawl floated 5 mm off the bracket and could not reach the lever. | Rest stop: a 30 mm bar between the bracket plates, under the crank arms. Rest catch (on the -Y plate) and end pawl (on the +Y plate): each a 12 mm spring pawl on a 16 mm shaft that turns in the bracket plate, with a release handle outside the plate, catching the crank pin at the start and at the end of the stroke. Crank pin 112 mm long. | The pawl lies on the line the crank pin moves when the lever kicks back, so the 47 J kickback pushes it end on; the catch does the same at the start, where the lever's weight would otherwise let it fall into the stroke. |
| P9 | The eject fork's tines and the 110 mm foot pin crossed the upper links at the end of the stroke. | One central eject arm, cut from 20 mm plate with a crank in it, whose round nose pushes on the push rod's foot; foot pin removed. Eject pivot at 160 mm from the axis and 607.5 mm up (was 620 mm), so the nose stays under the rod for the whole 160 mm lift. | The arm stays inside the rod's width, where no link passes. The lever ratio is unchanged (160 mm arm). |
| P10 | The two ties ran 45 to 85 mm off the centre line, through the crank pin's path. | Ties moved out to 90 mm off the centre line, welded along the bracket plates' outer faces, with 10 mm end tabs bolted by two M12 through the beam plate and the column flange. | The crank pin now clears them; the core can be unbolted from the base. |
| P11 | The linkage guard (BOM 13) was in the BOM but not drawn. | Guard modelled: expanded metal on a 20 x 20 x 3 mm angle frame, top and both sides over the crank, connecting link and ties; two M10 feet on the base plate, two M10 brackets with 35 mm spacers on each bracket plate. | It clears every moving part over the full stroke. |
| P12 | The lever pipe began inside the hub, and nothing kept it in its socket. | Pipe starts 46 mm from the hub centre; a 12 mm locking pin with an R-clip through socket and pipe. | The lever cannot slide out under load. |
| P13 | The 100 mm hub sat between bracket plates 120 mm apart with nothing to locate it. | 10 mm washers each side; shaft held by circlips. | Locates the crank and connecting link on the centre line. |
| P14 | The block gauge was a placeholder (legs 316 mm apart). | Legs 292 mm apart inside and a 93 mm notch in the top edge. | It now checks the longest and the tallest good block (R1). |
| P15 | The lever bracket plates had no room for the parts above. | Bracket plates reshaped (about 230 x 272 mm) to carry the shaft, rest stop, catch and pawl shafts and the ties. | One outline, cut twice as a mirror pair. |

*Table 2. Knock-on changes.*

| Item | Change | Reason |
| --- | --- | --- |
| Mass | Press 200.0 kg, heaviest piece 45.0 kg (was 187.0 kg and 36.6 kg) [EPR-CAL-001 section 8]. The total now counts the guard (5.5 kg) and the bolts (1.2 kg), which the concept left out. **R7's 190 kg total is not met** (10 kg over); its 50 kg piece limit is met. | Round link ends, lugs, base plate, guard, fixings. |
| Cost | BOM lines 1 to 7, 11 and 13 repriced: $520 against the $500 value-engineering target (`budget_usd`) [EPR-CAL-001 section 11]. **R13 is over the target by USD 20.** | Parts added for construction. `budget_usd` is not changed: see Table 3. |
| Calculations | EPR-CAL-001 v0.3: lid span 420 mm (lid SF 1.61 at the design load, was 1.84); link net section at the 41 mm bush hole (SF 2.33); new checks for the column at its access hole (SF 2.49) and the eject arm (SF 1.72). Lowest safety factor unchanged at 1.13 (bush bearing). | Follows the model. |
| Drawings | EPR-DWG-001 Rev P2; concept blueprint EPR-DWG-010 Rev P2; making sketches EPR-DWG-101 to 115 added. | Follows the model. |
| Documents | EPR-PRC-001 v0.5, EPR-REQ-001 v0.5, `bom/bom.csv`, `README.md`: mass, cost, latch, catch and eject descriptions. | Follows the model. |

*Table 3. Items proposed to Amish; A1 and A3 accepted on 2026-10-02.*

| # | Question | Options | Recommendation |
| --- | --- | --- | --- |
| A1 | R7 total mass: 200 kg against 190 kg. | (a) Relax the total to 200 kg and keep the 50 kg piece limit (heaviest piece 45 kg). (b) Lighten: a 16 mm lid plate with deeper ribs, 10 mm mold walls, a lighter base plate, perhaps 10 kg, then re-check. (c) Both. | (a), as for EPR-DDR-002 item 13: the piece limit is what governs moving the press. Accepted 2026-10-02: the R7 total is 200 kg, defined to include the guard and bolts; the 50 kg piece limit is kept. |
| A2 | R13 cost: $520 estimated against the $500 value-engineering target (a hypothetical control target), USD 20 over. | No decision needed. The target stays $500. Savings worth trying: a lighter press, and local quotes at TRL 4; plain pins without bushes would save about $30 but R8 fails. | Carry in the value engineering section of EPR-DEC-001. |
| A3 | The rest catch adds a step: the operator lifts it before each stroke. | (a) Hand release, as modelled. (b) A foot pedal linked to the catch. | (a) for the prototype; reconsider after timing cycles (R4). Accepted 2026-10-02: hand release, with the rule that the catch is in before the latch is opened; a foot pedal only if timed cycles show the extra step costs output. |

## Consequences

- `design_state: constructable` in `project.yaml`. The build plan EPR-BLD-001 shows every component and step in pictures generated from the model (`cad/src/build_plan_media.py`).
- Requirement status: R7 moved from met on paper to **not met** (A1); with A1 accepted on 2026-10-02 the total limit is 200 kg including the guard and bolts, so R7 is met on paper again (EPR-REQ-001) and R13 to **over the value-engineering target by USD 20** (A2); R2 and R4 stay at risk; R5, R1, R11 and R12 stay met on paper; R6 and R9 met by design review; R3, R8, R10 and R14 not verifiable at TRL 3.
- The photoreal renders (`media/render-*.png`), `media/card.png`, `media/social-preview.png` and the appearance model `cad/src/product_model.py` still show the concept's hinge knuckle, latch hook, eject fork and guide strap; they need updating on Amish's Mac, where Blender is.
- The UPN 80 section, bush sizes, socket tube and springs are confirmed when bought (register, "To confirm when parts are bought").

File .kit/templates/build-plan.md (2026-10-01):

---
doc_id: PRJ-BLD-001
title: Project prototype build plan
project: Project name
doc_type: Build plan
version: "0.1"
status: Draft
date: YYYY-MM-DD
author: Amish Chadha
license: CERN-OHL-S-2.0
revisions:
  - version: "0.1"
    date: YYYY-MM-DD
    author: Amish Chadha
    change: First build plan; design made constructable
---

# Project prototype build plan

**Plan, not yet built.** How to build the first proof-of-concept prototype, component by component. Building and testing to it is TRL 4 work. Decisions still to be made are kept in the design decisions register (`docs/06-design-decisions.md`), not here.

## 1. What you are building

Every component, pulled apart and numbered in build order

One short paragraph: what the prototype is, how many components, which are made and which are bought, and the main ways they are made.

## 2. What changed to make it buildable

| Component | The concept had | The buildable design has | Why |
| --- | --- | --- | --- |

## 3. Making the components

### 3.1 Component name

Making sketch

**What it is and what it is made from.**

**How to make it.**

1. Mark out ...
2. Cut ...

**How it fits the parts next to it.**

Close-up of the joint

**Check before moving on.**

## 4. Putting it together

### Step 1: ...

Step 1

## 5. First checks

| Check | Requirement | How | Pass when |
| --- | --- | --- | --- |

## 6. Safety stops

## 7. Tools, skills and workspace

## 8. Where the numbers come from

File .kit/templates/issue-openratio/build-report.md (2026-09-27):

---
name: Build report
about: Tell us what happened when you built, printed or tested part of this design
title: "Build report: "
labels: build-report
---

This is a research and educational prototype, not a medical device. It is a TRL 3 concept and is not released for fabrication. If you build any part of it, you do so at your own risk. Reports help everyone.

**What you built** (part, sub-assembly or test)

**Materials, tools and settings**

**What worked**

**What did not work, with photos or measurements if you have them**

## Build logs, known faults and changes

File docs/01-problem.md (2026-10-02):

---
doc_id: EPR-PRB-001
title: EarthPress problem statement
project: EarthPress
doc_type: Problem statement
version: "0.5"
status: Draft
date: '2026-10-02'
author: Amish Chadha
license: CERN-OHL-S-2.0
revisions:
- version: "0.1"
  date: '2026-09-25'
  author: Amish Chadha
  change: Initial scaffold
- version: "0.2"
  date: '2026-09-25'
  author: Amish Chadha
  change: Populate to TRL 2 (users, context, constraints, prior work with sources, open questions)
- version: "0.3"
  date: '2026-09-25'
  author: Amish Chadha
  change: Open questions updated after EPR-CAL-001 and EPR-DDR-001 (block size and stabilizer adopted for TRL 3; two operators needed on paper)
- version: "0.4"
  date: '2026-09-25'
  author: Amish Chadha
  change: Recommendations accepted by Amish (DDR-002)
- version: "0.5"
  date: '2026-10-02'
  author: Amish Chadha
  change: "Partner rule and first candidate; design soil and lime option; press mass (EPR-DEC-001, 2026-10-02)"
---

# EarthPress problem statement

Walls made of fired brick or cement block carry high embodied carbon and cost, and the cheaper, lower-carbon alternative, compressed stabilized earth blocks (CSEB), depends on a press that most small builders cannot buy or make. Open press designs exist, but the best documented one is hydraulic and costs thousands of dollars, while the manual lever presses that suit a village building site are sold as closed products or survive as old, undimensioned drawings. EarthPress aims to fill that gap with an open, welder-buildable manual press and a field soil test kit.

## Why it matters

- The buildings and construction sector accounts for about 32 % of global energy use and 34 % of global CO2 emissions ([UNEP, *Global Status Report for Buildings and Construction 2024/2025*](https://www.unep.org/resources/report/global-status-report-buildings-and-construction-20242025)).
- Cement production alone accounts for around 8 % of global CO2 emissions ([Chatham House, *Making Concrete Change*, 2018](https://www.chathamhouse.org/2018/06/making-concrete-change-innovation-low-carbon-cement-and-concrete)).
- UN-Habitat estimates that by 2030 about 3 billion people, about 40 % of the world's population, will need access to adequate housing, or about 96,000 new affordable units every day ([UN-Habitat, Housing](https://unhabitat.org/topic/housing)).
- 1.12 billion people lived in slums or informal settlements in 2022, 130 million more than in 2015 ([UN, *Sustainable Development Goals Report 2024*, Goal 11](https://unstats.un.org/sdgs/report/2024/Goal-11/)).
- The Auroville Earth Institute reports that CSEB stabilized with 5 % cement embody about 548 MJ/m³ and about 49 kg CO2/m³, against about 6,120 MJ/m³ and about 643 kg CO2/m³ for locally fired bricks, that is, about 11 times less energy and 13 times less pollution ([Auroville Earth Institute, CSEB](https://www.earth-auroville.com/compressed_stabilised_earth_block_en.php)).

## Users and context

EarthPress serves people who build small load-bearing or infill walls with the soil on or near their site.

| User | Need | Context |
| --- | --- | --- |
| Self-builders and families | Make their own walling for a one- or two-room house, a store or an extension | Peri-urban and rural sites with clay-sand soil; little cash, plenty of labor |
| Small block-making enterprises | Sell blocks locally as a business | A yard with shade, water and a stock of soil; a crew of three to five |
| NGOs and community builders | Train masons and build schools, clinics or reconstruction housing | Programs in sub-Saharan Africa, South Asia and Latin America |
| Local welders and fabricators | Build, repair and sell the press | A stick welder, angle grinder and drill press; steel from a local stockist |
| Architects and owner-builders in high-income countries | Low-carbon garden walls, studios and small buildings | Places with earthen building codes, such as New Mexico |

The press works outdoors on uneven ground, in dust, heat and rain, and is moved between sites on a pickup or by hand. Operators range from trained masons to first-time volunteers.

## Constraints

- Garage-buildable prototype for about $500 USD in parts (`project.yaml`), with no machining beyond drilling and purchased turned pins.
- Human powered: no electricity, hydraulics or engine on site.
- Parts from local steel stockists: flat bar, plate, channel, rectangular tube and pipe in common sizes.
- Wear parts and pins replaceable with hand tools.
- Movable by four people, or by two people once dismantled (EPR-CAL-001: about 187 kg in eight pieces).
- Blocks must meet a recognized strength reference for the intended use (for example Auroville class B, or the New Mexico code minimum of 300 psi, about 2.1 MPa) when made from suitable, tested soil.

## Out of scope

- Hydraulic or motorized presses, and block-making plant.
- Structural design of buildings, including seismic design; EarthPress supplies blocks, not building approval.
- Rammed earth, adobe and fired brick.
- Certification of blocks against any national standard (a later-stage activity with a test laboratory).

## Prior work

| Work | What it offers | Gap for EarthPress |
| --- | --- | --- |
| CINVA-Ram, a manual lever press designed by Raúl Ramírez at CINVA, Bogotá, in 1956 and patented in 1958 ([Botti, 2023](https://www.sciencedirect.com/science/article/pii/S2095263523000584)) | The original single-lever, bottom-piston press; widely copied | Low compaction by modern standards; drawings vary and are rarely open-licensed |
| Auroville Earth Institute and its Auram presses (India) | Mature CSEB practice: 5 % cement on average, compaction pressure of 2 to 4 MPa, strength classes; the Auram 3000 makes about 1,000 blocks a day ([Auroville Earth Institute](https://www.earth-auroville.com/compressed_stabilised_earth_block_en.php)) | Commercial presses; not open hardware |
| Open Source Ecology CEB Press | Open hardware (CC BY-SA 4.0, GPLv3), about 6 blocks a minute; materials cost $3,000 to $6,500, about $10,000 assembled ([OSE wiki](https://wiki.opensourceecology.org/wiki/CEB_Press)) | Hydraulic and engine powered; too costly for a self-builder |
| 2021 New Mexico Earthen Building Materials Code, 14.7.4 NMAC | Covers CEB; cured units need 300 psi compressive strength and 50 psi modulus of rupture, with five random units tested per project ([NM Commission of Public Records](https://www.srca.nm.gov/parts/title14/14.007.0004.html)) | A strength target, not a press design |
| Interlocking stabilized soil block (ISSB) presses used in East Africa | Mortar-saving interlocking blocks | Specific block geometries; mostly commercial presses |

## User research and co-design

This design is for communities the author is not part of, so requirements come from the people who will use it.

- [ ] Identify a local partner organization. Decided on 2026-10-02 (EPR-DEC-001): a partner that already trains builders in stabilized earth blocks and has local soils and cement supply; first candidate to approach, the Auroville Earth Institute in India. Nothing is agreed yet.
- [ ] Run co-design sessions with intended users; record who, where and what was learned
- [ ] Validate load, distance, terrain and cost assumptions in the field
- [ ] Revise requirements (REQ) from findings before freezing the design

## Open questions

- The flat 290 x 140 x 90 mm block was decided by Amish on 2026-09-25 (EPR-DDR-001 item 3, EPR-DDR-002). Do local masons prefer it, a larger module or an interlocking block?
- EPR-CAL-001 finds that one operator pulling 500 N reaches only about 0.5 MPa and that two people are needed on the lever for 2 MPa. Amish decided on 2026-09-25 to go with a two-person T-handle (EPR-DDR-002); co-design should still confirm that builders accept it rather than a lower pressure and more cement.
- Which soils in the first partner region pass the field tests, what cement or lime content do they need, and how stiff are they in the press? Until they are measured, the operating chart uses the softer soil (809 N, 405 N per operator), and lime is a documented option with its own chart and longer curing (decided 2026-10-02).
- What block strength do local building rules or funders require, and who will test blocks?
- How far do blocks and the press travel, and on what vehicle? The press is about 200 kg with its guard and bolts, in pieces of 45 kg or less (R7 total set at 200 kg on 2026-10-02).

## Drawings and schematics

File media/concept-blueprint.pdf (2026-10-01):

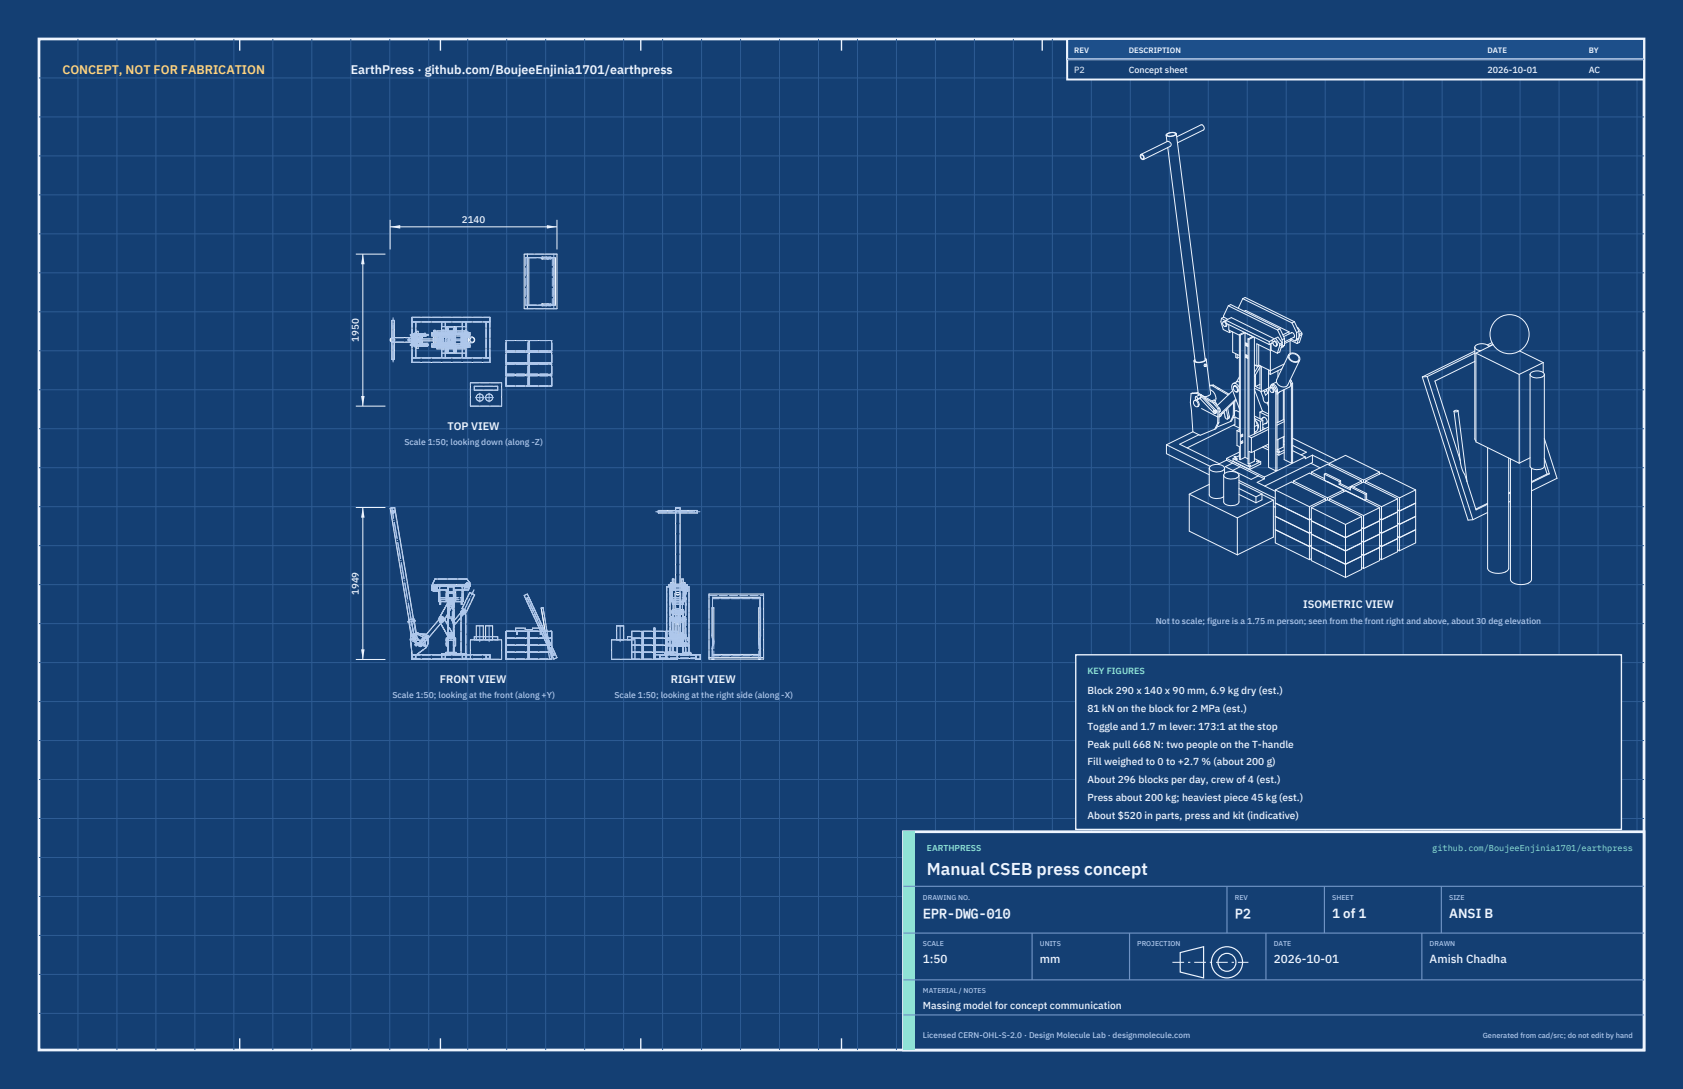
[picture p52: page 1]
CONCEPT, NOT FOR FABRICATION; EarthPress · github.com/BoujeeEnjinia1701/earthpress; FRONT VIEW; TOP VIEW; RIGHT VIEW; ISOMETRIC VIEW; REV; DESCRIPTION; DATE; Concept sheet; EARTHPRESS; github.com/BoujeeEnjinia1701/earthpress; DRAWING NO. EPR-DWG-010; REV P2; SHEET 1 of 1; SIZE ANSI B; SCALE 1:50; UNITS mm; PROJECTION; DRAWN Amish Chadha; Licensed CERN-OHL-S-2.0 · Design Molecule Lab · designmolecule.com; Generated from cad/src; do not edit by hand

Scale 1:50; looking down (along -Z)

Not to scale; figure is a 1.75 m person; seen from the front right and above, about 30 deg elevation

KEY FIGURES
Block 290 x 140 x 90 mm, 6.9 kg dry (est.)
81 kN on the block for 2 MPa (est.)
Toggle and 1.7 m lever: 173:1 at the stop
Peak pull 668 N: two people on the T-handle
Fill weighed to 0 to +2.7 % (about 200 g)
About 296 blocks per day, crew of 4 (est.)
Press about 200 kg; heaviest piece 45 kg (est.)
About $520 in parts, press and kit (indicative)

Scale 1:50; looking at the front (along +Y)

Scale 1:50; looking at the right side (along -X)

Manual CSEB press concept

MATERIAL / NOTES
Massing model for concept communication

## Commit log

2026-09-25 Initial scaffold: standard open hardware layout, CERN-OHL-S v2 + MIT licenses
    Claude-Session: https://claude.ai/code/session_01XuhhSU4W6fYhgCfURbrkut
    [bom.csv]
2026-09-25 Populate to TRL 2: problem, requirements, precis, concept media, BOM and README use cases
    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
    [bom.csv]
2026-09-26 Advance to TRL 3: DDR-001, CAL-001 sizing, parametric model with STEP/STL, GA drawing, priced BOM; TRL 4 on hold
    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
    [bom.csv, earthpress-assembly.step, earthpress-assembly.stl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]
2026-09-26 Accept all recommendations (DDR-002), switch footer to designmolecule.com, add README write-up with new inspiration point
    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
    [earthpress-assembly.step, earthpress-lid.step, earthpress-mold.step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]
2026-09-27 Product appearance model and photoreal renders
    Adds cad/src/product_model.py (appearance model for renders only, all main
    dimensions from model.py) and Blender renders in media/render-*.png,
    captioned with the project, repository and viewing direction. README leads
    with the product render; trl stays 3.
    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
2026-10-01 Image quality pass: legible exploded views, flow diagrams and drawing sheets
    Kit 1.6.1 image layout: the parts list sits in its own column, number bubbles sit on visible parts and never overlap, small parts get a leader, pictures are cropped to the subject, flow labels keep numbers with their units, and sheet captions and the revision table no longer overprint. Concept images, blueprint and general arrangement sheet regenerated; repo-specific labels moved clear of other text and lines.
2026-10-01 Kit 1.7.0: constructable design, illustrated build plan and design decisions register
    The design is now constructable: every part can be made and fits its neighbours, with each change recorded in a Design for construction decision record (made under Amish's 2026-09-30 instruction; ope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
    [bom.csv, earthpress-assembly.step, earthpress-assembly.stl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]
2026-10-02 Record Amish's approval of the open-decision recommendations
    Amish approved the recommendation on every open decision in the design decisions register ("i approve your recommendations for all 555 open decisions.", 2026-10-02). Each decision is moved to Decisio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
2026-10-03 Carry approved follow-ups into the design and redo photoreal renders
    Amish approved the follow-up actions from the open-decision sign-off ("APPROVED CHANGES, COMPLETE THESE", 2026-10-02), the design-for-construction change tables in ten repos, the last wave's open dec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
    [bom.csv, earthpress-assembly.step, earthpress-assembly.stl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]
2026-10-29 Kit 1.9.1 upgrade: pipeline documents and detailed CAD for every option
    STEM check with fixes under the standing instruction and an independent
    review, concept options scored against the user requirements, URS, PRS,
    RTM, REG, FEA, RSK, MKT, PLN and DDR, every option modelled at D3 with
    cad/fidelity.json passing, and the concept options picture rendered with
    Blender Cycles on Amish's Mac. Concept choices stay proposed, awaiting
    Amish.
    Claude-Session: https://claude.ai/code/session_01LppsZSzPTJWTBAV5wh1Goq

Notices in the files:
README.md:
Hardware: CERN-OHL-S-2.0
